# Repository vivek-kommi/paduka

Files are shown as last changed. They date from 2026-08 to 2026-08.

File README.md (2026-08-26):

# Paduka

A prosthetic limb designed to be shown, not hidden.

A below-knee prosthesis in six printed pieces, standing on an ornamented
*paduka* — the carved sole-and-toe-knob sandal that is one of the oldest
forms of footwear in India, and which never once pretends to be a bare foot.
Block-printed ornament, a working single-axis ankle, and a wood-fibre
biopolymer, on a printer that fits on a bench.

**→ [The site](https://vivek-kommi.github.io/paduka/)**

Submitted to the [British Cræft Prize](https://www.nationofartisans.com/prize), 2026.

---

## What is actually here

Three things, and the interesting one is the second.

**A printable outer form.** Cuff, shank, ankle, foot, paduka. Six pieces,
420 mm, about 2.3 litres of material, assembling without tools.

**A system that generates the ornament.** Not a picture wrapped round a
standard foot: the drawing is laid out in an unrolled (u, v) chart, cut into
separate blocks the way a Sanganeri print is cut, and turned into real
geometry — each dye a recess in the ground with a plug that fills it flush.
Six traditions are implemented, and each one is worked in zones up the leg
rather than tiled flat, because that is how the cloth it comes from is made
up.

**A joint.** The foot parts at the malleoli into a single-axis ankle: a 6 mm
pin in double shear, about ±9° of travel, and a bumper either side of the pin
doing the tuning.

## Why it is built the way it is

On a multi-material printer, colour is **not** charged per motif. It is
charged **per layer**. Any layer containing two filaments costs one tool
change and one purge, whether it carries a whole paisley or a single dot. A
420 mm object at 0.2 mm is about 2,100 layers, so an all-over repeat is on the
order of 1.9 kg of purge for a 2.1 kg object.

That single fact decides nearly everything about the printed drawing: the
ornament is gathered into worked borders with plain single-filament ground
between them, motifs are laid out by *count* rather than pitch so nothing is
ever sliced at the seam, and nothing is printed in an ink colour where it
cannot be seen. `print_plan.md` has the arithmetic.

## Layout

```
index.html            the site — one self-contained file, no network needed
print/                six 3MFs, one per piece, filaments already assigned
src/                  the generator
  paduka_stack.py     the master assembly: cuts the modules, drives the pattern
  paduka_paisley.py   the block library — buta, hashiya, phool, chownk
  paduka_ankle.py     the single-axis joint
  paduka_foot.py      the anatomical foot
  paduka_print.py     inlay, and the 3MF writer
  site/               the web build: patterns, payload, renderer
  print_plan.md       orientation, support, settings, assembly, clearances
```

## Running it

```
pip install trimesh manifold3d shapely numpy pillow matplotlib
cd src
python paduka_stack.py            # cut the modules, report volumes
python paduka_print.py madder     # write the print files
```

The site:

```
cd src/site
python web_pattern.py             # bake the six ornament traditions
python build_payload.py           # geometry + textures + palettes
python build.py                   # one HTML file
```

## Honest status

Works and is measured: the ornament engine, the printed prototype, the ankle's
travel.

Not done: stiffness and energy return have not been measured against
established prosthetic feet; the lime-derived composite the project actually
wants does not exist commercially; clinical validation needs partners.

**This is a printed prototype with correct attachment geometry. It is not a
certified load-bearing prosthesis and is not presented as one.**

Note on `print/`: those six files predate the pass that cut the foot from 82%
of layers carrying ink down to 31%, and from three inks to one. Regenerate
with `paduka_print.py` rather than trusting them for a long print.

## Credit where it is owed

The Jaipur Foot was developed in 1968 by the surgeon P. K. Sethi and the
craftsman Ram Chandra Sharma. Sethi received the Magsaysay Award and the Padma
Shri. Sharma, who made it, was barely credited. A craft prize is the right
place to say that the maker should be named.

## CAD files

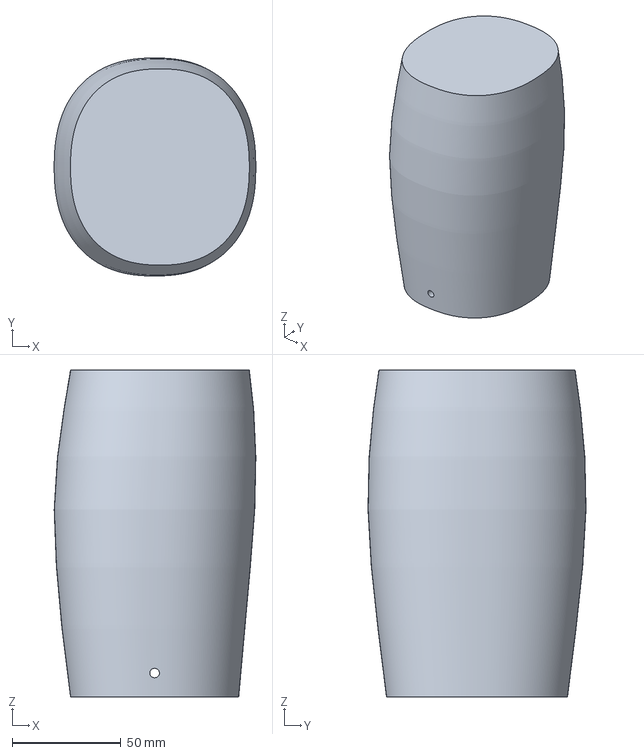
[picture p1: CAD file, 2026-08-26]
print/5_cuff.3mf
92.5 x 100.0 x 150.0 mm

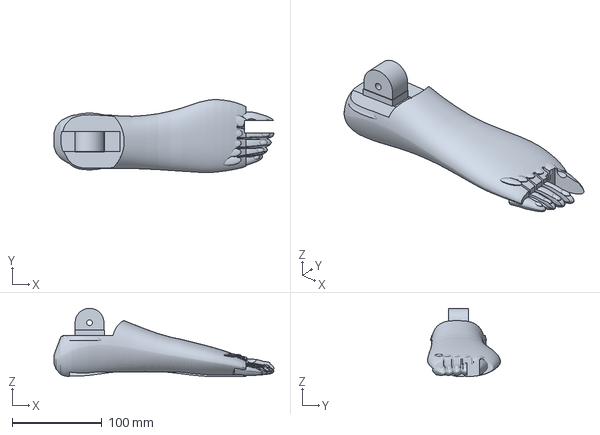
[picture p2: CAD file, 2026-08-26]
print/2_foot.3mf
244.5 x 81.0 x 76.0 mm

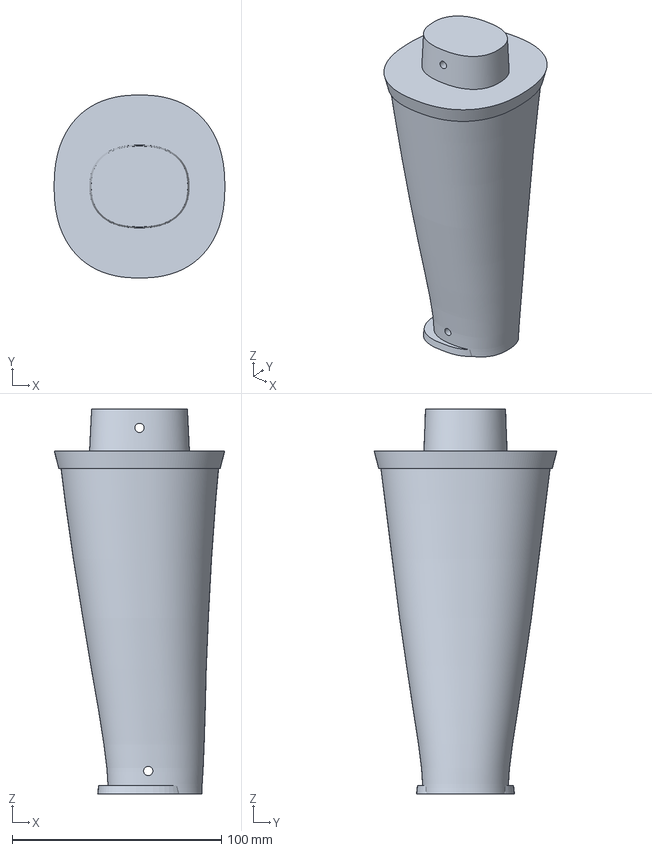
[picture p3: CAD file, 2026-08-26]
print/4_shank.3mf
81.5 x 87.4 x 184.0 mm

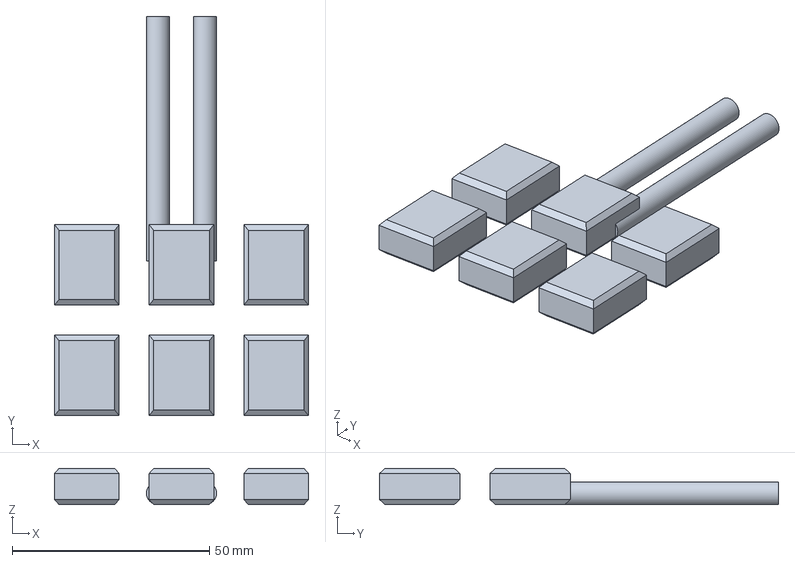
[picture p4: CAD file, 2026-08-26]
print/6_bumpers_and_pins.3mf
64.4 x 101.2 x 9.20 mm

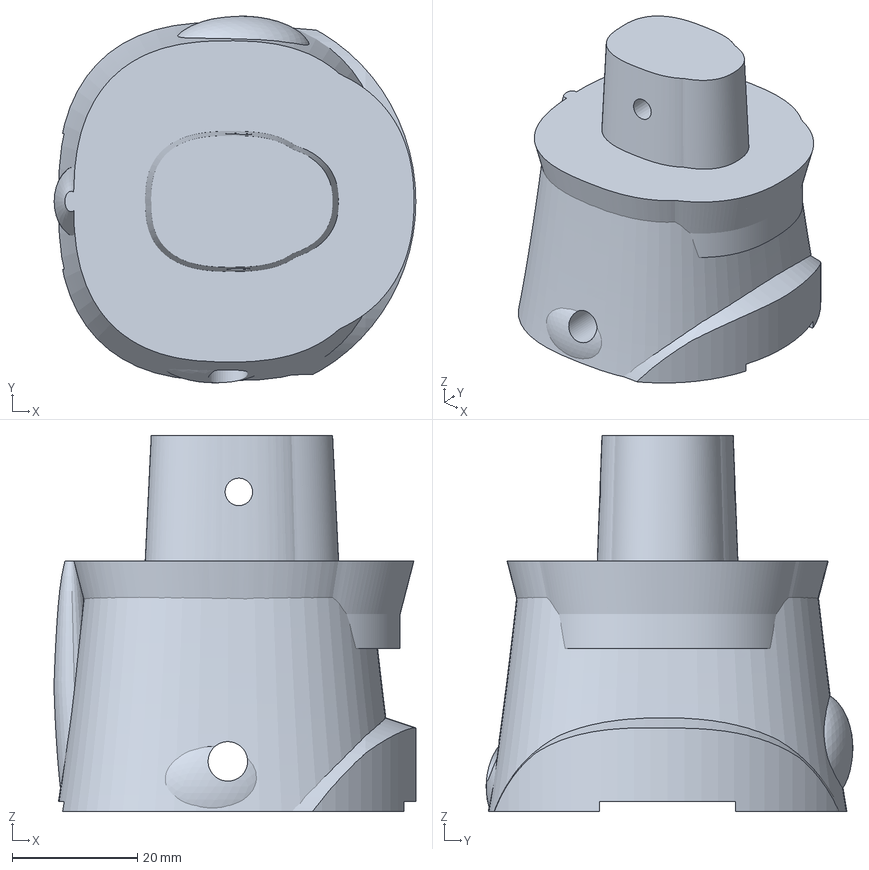
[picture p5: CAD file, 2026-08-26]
print/3_ankle.3mf
57.7 x 58.5 x 60.0 mm

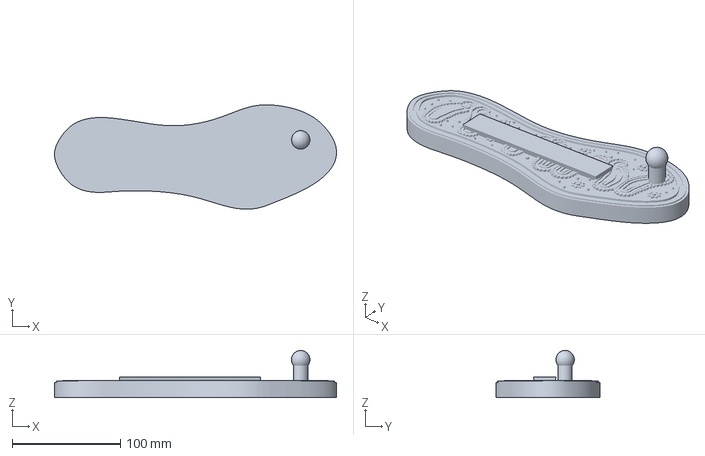
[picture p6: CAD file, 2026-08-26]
print/1_paduka.3mf
260.0 x 96.2 x 43.6 mm

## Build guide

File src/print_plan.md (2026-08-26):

# Paduka Stack — print and assembly

Six printed pieces make one 420 mm below-knee limb, with a working single-axis
ankle, standing on an ornamented paduka. Everything below assumes a **Bambu
P1S with the AMS**, a 0.4 mm nozzle, 0.2 mm layers and a 256 × 256 mm plate.

---

## The pieces

| # | File | Piece | Bed footprint | Height | Material |
|---|---|---|---|---|---|
| 1 | `1_paduka.3mf` | sandal | 260 × 96 mm | 44 mm | 281 cc |
| 2 | `2_foot.3mf` | foot | 244 × 81 mm | 76 mm | 454 cc |
| 3 | `3_ankle.3mf` | ankle block | 58 × 59 mm | 60 mm | 86 cc |
| 4 | `4_shank.3mf` | shank | 82 × 87 mm | 184 mm | 543 cc |
| 5 | `5_cuff.3mf` | cuff | 93 × 100 mm | 150 mm | 991 cc |
| 6 | `6_bumpers_and_pins.3mf` | 6 bumpers, 2 pins | 64 × 101 mm | 9 mm | 21 cc |

Files 1–5 open as **one object with several parts**, already assigned to
filaments. Do **not** "split to objects" — the parts are meant to be co-printed
in register, which is the whole point. File 6 is one filament.

---

## The ankle

The stack used to have a rigid ankle. A foot that cannot move at the ankle has
to be walked on by rolling over its toe, which is what makes a cheap
prosthetic foot read as a peg. So the foot now comes apart at the malleoli
into the joint a real single-axis foot has:

| | |
|---|---|
| axis | z = 74 mm — malleolus height, because the malleoli *are* the axis |
| pin | 6 mm, in a 6.3 mm bore, double shear through a 22 mm boss |
| travel | about ±9°, set by the bumpers, not by a hard stop |
| rear bumper | compresses as the heel lands, so the foot comes flat instead of slapping |
| front bumper | compresses as you roll over it and pushes back as you leave — the energy return |

The ankle block is a **column standing in a recess** in the top of the foot,
not a flange on a flat cut. A flat parting plane at this height hands the
ankle block 80 mm of instep as a thin fragile wing; a column in a socket is
both stronger and what an ankle actually looks like. The recess is cut back
8.5 mm all round, which is the column's sweep at full travel.

**The bumpers are the tuning.** Print them in TPU if you have it. In PLA, two
walls and 12% gyroid gives a surprisingly good spring. They are 3 cc each, so
the file gives you six: print a set at 8%, 12% and 20% and walk on the pair
you like.

**The pins lie down on the plate.** A pin is loaded in bending across its
axis; printed standing on end it is a stack of discs held together by layer
adhesion alone. A 6 mm stainless dowel or an M6 bolt is better still.

---

## What decides the ornament

On a multi-material printer, colour is **not** charged per motif. It is
charged **per layer**. Any layer containing two filaments costs one tool
change and one purge, whether it carries a whole paisley or a single dot.

A 420 mm object at 0.2 mm is about 2,100 layers, so an all-over repeat is of
the order of **1.9 kg of purge for a 2.1 kg object**. No flush tuning fixes a
factor of two. So the ornament is **banded**: worked borders — a heavy rule, a
run of butas, a dotted line, a closing rule — with plain single-filament
ground between them. One worked band per module, plus a rule at each seam, a
vamp band across the instep and a welt at the sole.

Each band is laid out by **count**, not pitch. The horizontal axis of the
drawing is an unrolled circumference, so its two ends are the same line — the
seam down the back of the leg. A fixed pitch almost never divides that
circumference evenly, so the last stamp before the seam collides with the
first one after it and a buta comes out sliced in half. Dividing the
circumference into *n* equal cells and centring a stamp in each puts the seam
exactly halfway between two stamps, where nothing is. The foot has a different
circumference from the limb, so it gets its own count. Nothing is ever cut.

Two more decisions follow from the same arithmetic:

- **Two inks on the limb, not three.** The detail block is gone; what it used
  to draw is left as bare ground showing through, which is what a resist print
  *is* — the pattern you see is the dye that did *not* reach the cloth.
- **Nothing is printed in an ink colour where it cannot be seen.** Spigots,
  socket bores, seam flats, collar faces, the dovetail channel, the toe-post
  cleft, and every face of the ankle joint are held at the ground filament. A
  mating face is therefore always one material, so tolerance never drifts with
  colour.

The **paduka keeps all four filaments** and keeps its relief proud. It is
44 mm tall instead of 420, so its polychrome costs almost nothing, and a
sandal you stand on wants ornament that wears in rather than fills up.

---

## Why the ink is 1.5 mm deep, and the lines 1.7 mm wide

The first version had a 0.45 mm inlay and 1.2 mm lines, and it sliced into a
dotted mess: filament 2 printed **5.5 g of model and flushed 71 g**.

On a vertical wall an inlay is only as wide as it is deep, and the slicer lays
perimeters 0.42 mm wide. At 0.45 mm the pattern was thinner than a single
extrusion, so most of it was dropped. The fix is arithmetic, not taste:

| | |
|---|---|
| inlay depth | **1.5 mm** — deeper than the whole wall stack (2 loops = 0.87 mm, 3 = 1.29 mm), so every perimeter inside a motif is ink |
| minimum line | **1.7 mm** — four extrusions across the thinnest thing in the drawing |
| register gap | **1.25 mm** — three extrusions of clear ground between two dyes, or they smear |

Verified on the drawing itself: **0.0% of the ink is thinner than 1.7 mm.**
The same slice now prints 32.5 g of filament 2 instead of 5.5 g.

The pattern is **inlaid, not embossed**, on the limb: the ground carries
recesses and the plugs fill them flush. A plug's outer face *is* the original
surface, so the two can never drift apart, and there is no boolean to fail on
a million-face mesh. Bambu will warn about non-manifold edges on those parts —
that is the ground and the plugs sharing their interface exactly, which is
what flush means. It slices fine.

---

## Orientation and support

- **paduka** — flat, ornament up. 260 mm long on a 256 mm plate, so **rotate
  45°**; the rotated box is about 198 × 203 mm. No support.
- **foot** — sole down, as it sits on the sandal. The dovetail channel, the
  toe-post cleft and the bumper pockets face downward: **support, tree,
  build-plate only**, threshold 30°.
- **ankle block** — fork downward, spigot up. The fork slot and the pin bore
  need **support inside the part** — set support to *everywhere*, not
  build-plate only, for this one piece.
- **shank** and **cuff** — seam face down, spigot up. The flat seam ring is
  the best adhesion surface on the model and every overhang above it is under
  10°. **No support.**
- **bumpers and pins** — flat. Brim on the pins.

---

## Settings that matter on the AMS

| Setting | Value | Why |
|---|---|---|
| Layer height | 0.2 mm | at 0.28 the fine work in the borders drops below one extrusion |
| Wall loops | 2 or 3 | either works; the 1.5 mm inlay covers both |
| Flush multiplier | **1.0** | 1.4 is very conservative; below 0.8 the cream shows navy |
| Flush into support | **on** | the foot and ankle have support anyway |
| Flush into object infill | **off** | it moved 56 g out of the purge but put 185 g of extra plastic into the part — a net loss on this geometry. Test it yourself before trusting either way |
| Prime tower | 45 mm, in a **corner** | the default position collides with the rotated paduka |

Print the pieces **one at a time**. Two multi-material objects on one plate
double the tool changes for no benefit.

---

## Assembly

1. **Bumpers into the foot.** Drop one into each pocket either side of the
   boss. They stand 6 mm proud.
2. **Ankle block onto the foot.** The fork straddles the boss; line up the
   bores and push the pin through. Snug, not tight — the joint should fall
   through its own travel under its own weight.
3. **Foot onto the paduka.** Hold it 20° nose-up, engage the dovetail rail at
   the heel, slide forward until the khadau post comes up through the cleft
   between the great toe and the second. It stops itself. One hand, no tools.
4. **Shank onto the ankle block.** The spigot is an oval, so it only goes on
   one way round. Push down until the shank's seam ring sits on the collar —
   a visible 2 mm shoulder, which is the printed band you can see in the
   pattern. Pin it.
5. **Cuff onto the shank.** Same again.

To change paduka, slide the foot backwards off the rail with the limb still
attached. To break the limb down for a case, pull the three pins.

---

## Clearances

| | |
|---|---|
| ankle boss to fork | 0.35 mm on every face |
| ankle pin | 6.3 mm bore for a 6 mm pin |
| ankle working gap | 6.0 mm at neutral, ±9° of travel |
| ankle recess | 8.5 mm all round — the column's sweep |
| spigot to socket | 0.32 mm |
| dovetail and toe post | 0.35 mm |
| seam pin | 4.4 mm bore for a 4 mm pin |
| register gap between two dyes | 1.25 mm |
| minimum ink width | 1.7 mm |

If your printer runs tight, change the clearance, not the part: `ANK_CLEAR`
in `paduka_ankle.py`, `CLEAR` in `paduka_stack.py`, `MOD.CLEAR` in
`paduka_modular.py`.

---

## If you want it cheaper

`LIMB_BANDS` and `FOOT_BANDS` in `paduka_stack.py` name every band position by
hand. In order of how much they save:

1. **Drop a band.** Deleting either entry in `LIMB_BANDS` takes its layers out
   entirely; deleting `FOOT_BANDS` saves the most.
2. **Print the limb plain and the paduka polychrome.** One filament on the
   limb, the whole wardrobe in the shoes — several paduka in several
   colourways, one foot. This is the project's own argument ("you own one foot
   and several paduka") and it takes the limb's purge to nil. The **Undyed**
   button in the viewer shows exactly this.

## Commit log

2026-08-26 Add the generator: assembly, block library, joint, print writer
2026-08-26 Add print files: paduka, ankle, bumpers and pins
2026-08-26 Add print file: shank
    [4_shank.3mf]
2026-08-26 Add print file: foot
    [2_foot.3mf]
2026-08-26 Add print file: cuff
    [5_cuff.3mf]
